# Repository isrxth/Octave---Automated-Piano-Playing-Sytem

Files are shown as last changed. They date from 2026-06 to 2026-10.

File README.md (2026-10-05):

###### 🎹 Project Octave

###### 

###### By Team WeBeSyncing

###### 

###### Project Octave is a high-speed, polyphonic, CNC-style robotic piano playing system. Utilizing a multi-microcontroller architecture, ESP-NOW wireless synchronization, and a custom lookahead kinematic engine, Octave translates standard .mid files into precise physical movements, playing an acoustic piano with superhuman speed and accuracy.

https://github.com/user-attachments/assets/f8b78fd2-65e9-428f-8b61-9593326f1c79

###### ✨ Key Features

###### 

###### &#x20;   Polyphonic "Cluster" Engine: Groups simultaneous MIDI notes and calculates a "Center of Gravity" offset, allowing a rigid solenoid block to perfectly strike multiple keys at once.

###### 

###### &#x20;   Anti-Flood Staggering: Automatically spaces out simultaneous polyphonic WebSocket commands by 15ms to prevent Arduino Uno serial buffer overflow and dropped notes.

###### 

###### &#x20;   Lookahead Background Pre-Positioning: The Web UI calculates future moves and silently drives the stepper carriages into position during the natural musical rests, eliminating mechanical latency.

###### 

###### &#x20;   Strict Hardware Interlock: A closed-loop feedback system using ESP-NOW guarantees that solenoids will never fire while the carriage is in transit, completely protecting the 3D-printed mounts from lateral shear forces.

###### 

###### &#x20;   Dynamic Velocity Control: Maps MIDI velocity data to hardware PWM duty cycles, allowing for expressive, dynamic play (Soft vs. Hard strikes), or strict binary toggling.

###### 

###### &#x20;   Asynchronous Web UI: A beautiful, dark-mode TailwindCSS web interface hosted directly on the ESP32. Features live BPM scaling, dynamic clearance tuning, and an interactive virtual keyboard.

###### 

###### &#x20;   Over-The-Air (OTA) Updates: Fully integrated ElegantOTA allows for flashing firmware to the embedded microcontrollers via Wi-Fi without dismantling the piano hardware.

###### 

###### 🧠 System Architecture

###### 

###### Octave uses a distributed computing model to ensure non-blocking, real-time performance.

###### 1\. The Master Node (ESP32)

###### 

###### &#x20;   Hosts the Web UI (test.html) via ESPAsyncWebServer.

###### 

###### &#x20;   Receives WebSocket commands from the user's browser.

###### 

###### &#x20;   Directly drives the Black Key Solenoids (S1 - S5) via hardware PWM.

###### 

###### &#x20;   Broadcasts MOVE commands to the Stepper Node over ESP-NOW.

###### 

###### &#x20;   Sends Serial commands to the Arduino Uno.

###### 

###### 2\. The Stepper Node (ESP32)

###### 

###### &#x20;   Listens for ESP-NOW packets and drives two NEMA 17 stepper motors using AccelStepper.

###### 

###### &#x20;   Motor 1 (White Carriage): Uses sliding-window nearest-neighbor logic to traverse the white keys.

###### 

###### &#x20;   Motor 2 (Black Carriage): Uses inverted, octave-locked kinematics to perfectly align with the irregular 2-and-3 black key clusters.

###### 

###### &#x20;   Reads physical limit switches and transmits AT\_TARGET packets back to the Master to unlock the software thread.

###### 

###### 3\. The Strike Node (Arduino Uno)

###### 

###### &#x20;   Receives ultra-fast Serial packets from the Master ESP32 via a logic level shifter.

###### 

###### &#x20;   Manages a non-blocking 40ms ballistic state machine for the 7 White Key Solenoids.

###### 

###### &#x20;   Utilizes a custom 1kHz Software PWM engine for digital pins to maintain a 23% low-current hold state, preventing coil burnout.

###### 

###### 🛠️ Hardware Requirements

###### 

###### &#x20;   2x ESP32 Development Boards

###### 

###### &#x20;   1x Arduino Uno R3

###### 

###### &#x20;   2x NEMA 17 Stepper Motors (w/ TMC2209 or A4988 Drivers)

###### 

###### &#x20;   12x 15N Push-Pull Solenoids

###### 

###### &#x20;   3D-Printed Carriages \& Solenoid Mounts

###### 

###### &#x20;   12V / 24V Power Supplies \& Logic Level Converters (HW-209)

###### 

###### 🛜 Changing the Wi-Fi Network Name (SSID)

###### 

###### By default, the Master ESP32 creates a hotspot named POCOF3. Because the Master and Stepper nodes must communicate, their network credentials must match perfectly.

###### 

###### &#x20;   Open solenoid\_esp.cpp (Master) and modify:

###### &#x20;   C++

###### 

###### &#x20;   const char\* hotspotSSID     = "Project\_Octave"; // Your new name

###### &#x20;   const char\* hotspotPassword = "00000000";       // Your new password

###### 

###### &#x20;   Open stepper\_esp.cpp (Stepper) and ensure lines 8 \& 9 match exactly.

###### 

###### &#x20;   Re-flash both ESP32s.

###### 

###### 🚀 Installation \& Setup

###### 1\. Flash the Firmware

###### 

###### &#x20;   Open the project in PlatformIO or the Arduino IDE.

###### 

###### &#x20;   Install the required libraries: ESPAsyncWebServer, AsyncTCP, AccelStepper, ElegantOTA.

###### 

###### &#x20;   Flash solenoid\_esp.cpp and stepper\_esp.cpp to your respective ESP32s.

###### 

###### &#x20;   Flash solenoid\_uno.ino to your Arduino Uno.

###### 

###### 2\. Connect to the UI

###### 

###### &#x20;   Power on the Master ESP32.

###### 

###### &#x20;   Connect your computer/tablet to the Octave Wi-Fi hotspot.

###### 

###### &#x20;   Open your web browser and navigate to the ESP32's IP address (default: http://192.168.4.1).

###### 

###### &#x20;   Enter the IP into the Master Control UI and click CONNECT WS.

###### 

###### 🎹 Polyphony Limits \& Hardware Constraints

###### 

###### While the software fully supports polyphonic MIDI playback, it is bound by the physical laws of the rigid 3D-printed solenoid blocks.

###### 

###### &#x20;   The Span Limit: The system can play multiple notes at the exact same time, but they must physically fit under the 7-solenoid white carriage or the 5-solenoid black carriage. \* The Outlier Drop: If a MIDI file demands a C3 and a C5 simultaneously, the carriage cannot stretch. The software's Cluster Engine will calculate a "Center of Gravity" to cover the densest cluster of notes and safely ignore the unreachable outliers to prevent the motors from destroying the mounts.

###### 

###### 🎯 Usage \& Tuning

###### 

###### Once connected to the UI, you can calibrate Octave to match your specific physical build:

###### 

###### &#x20;   White Home / Black Home: Adjust these steps to perfectly align the 3D-printed carriages over the physical C3 octave. (Note: Black Home uses inverted kinematics, so its home step is a high value like 2400).

###### 

###### &#x20;   Clearance (ms): The mechanical time allowed for the 15N solenoid springs to pull the metal slugs out of the keybed before the stepper motors are allowed to move. Lower this value for faster songs, but ensure the slugs clear the keys to avoid lateral dragging.

###### 

###### &#x20;   Target BPM: The live tempo scaler. You can speed up or slow down a loaded MIDI file in real-time.

###### 

###### 📝 License \& Credits

## Schematics & PCB

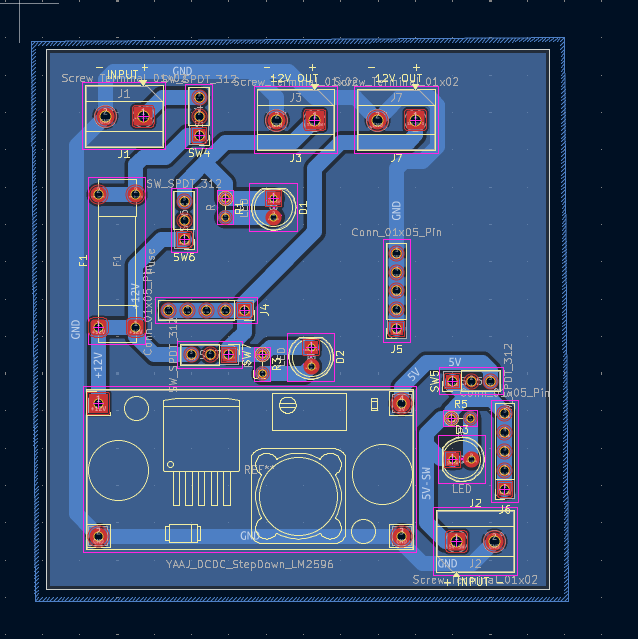
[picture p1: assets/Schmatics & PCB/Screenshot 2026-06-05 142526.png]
Schematic and PCB overview


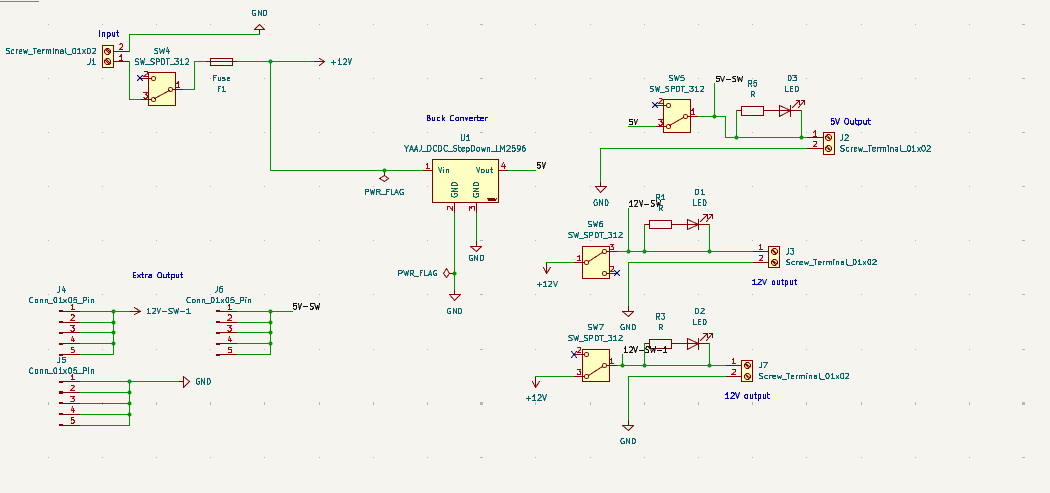
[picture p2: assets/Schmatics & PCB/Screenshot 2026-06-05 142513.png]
Schematic detail


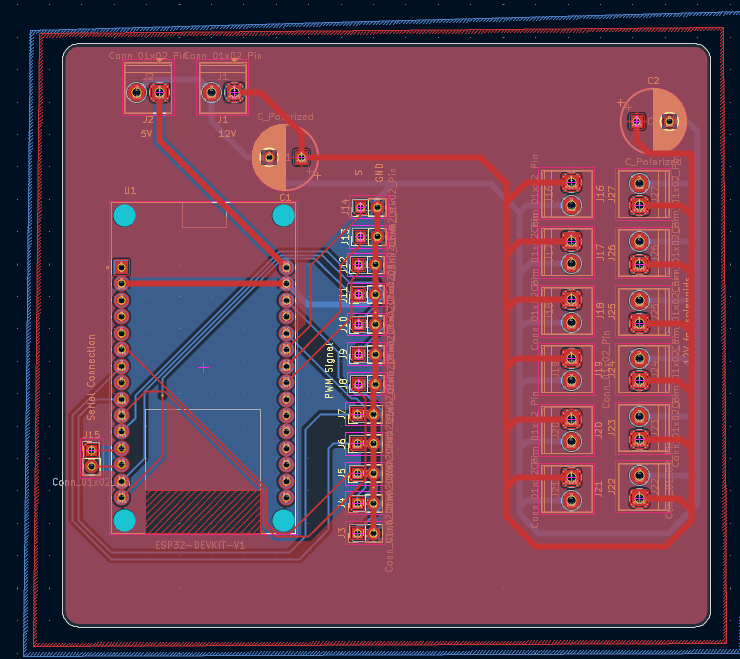
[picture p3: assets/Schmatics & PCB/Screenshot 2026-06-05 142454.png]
PCB detail


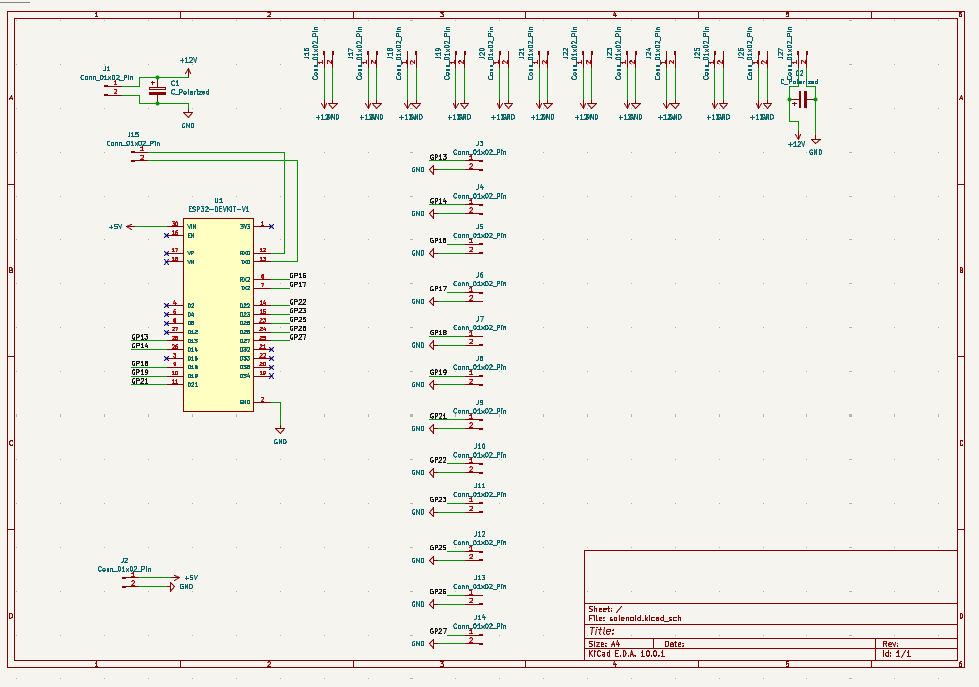
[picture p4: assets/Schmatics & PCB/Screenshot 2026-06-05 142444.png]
Power board schematic


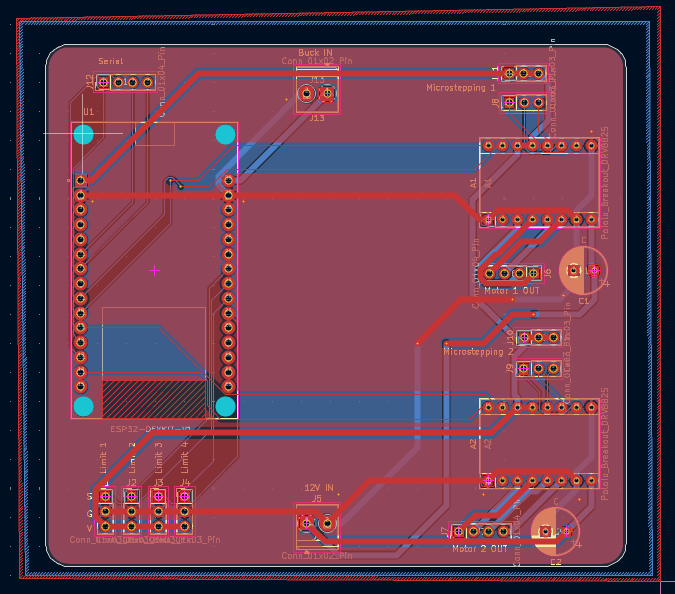
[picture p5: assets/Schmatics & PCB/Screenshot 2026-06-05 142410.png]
Solenoid board schematic


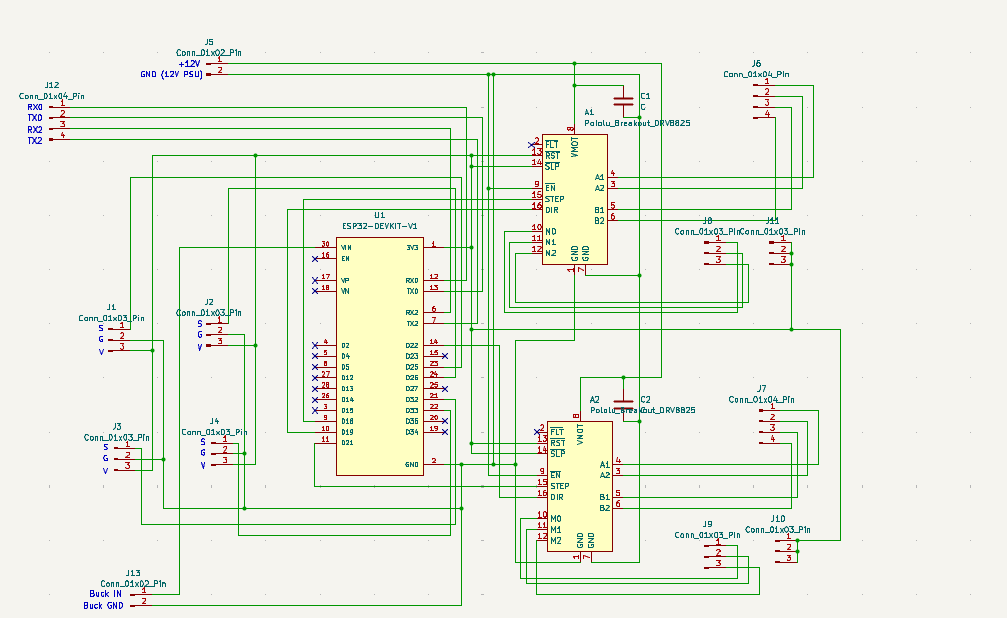
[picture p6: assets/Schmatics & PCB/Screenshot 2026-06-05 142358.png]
Stepper board schematic


###### 

###### Developed by Team WeBeSyncing.

###### Built for the intersection of Embedded Systems, Mechanical Engineering, and Music.

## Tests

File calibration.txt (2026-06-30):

C 810
D 800
E 780
F 770
G 750
A 750
B 730

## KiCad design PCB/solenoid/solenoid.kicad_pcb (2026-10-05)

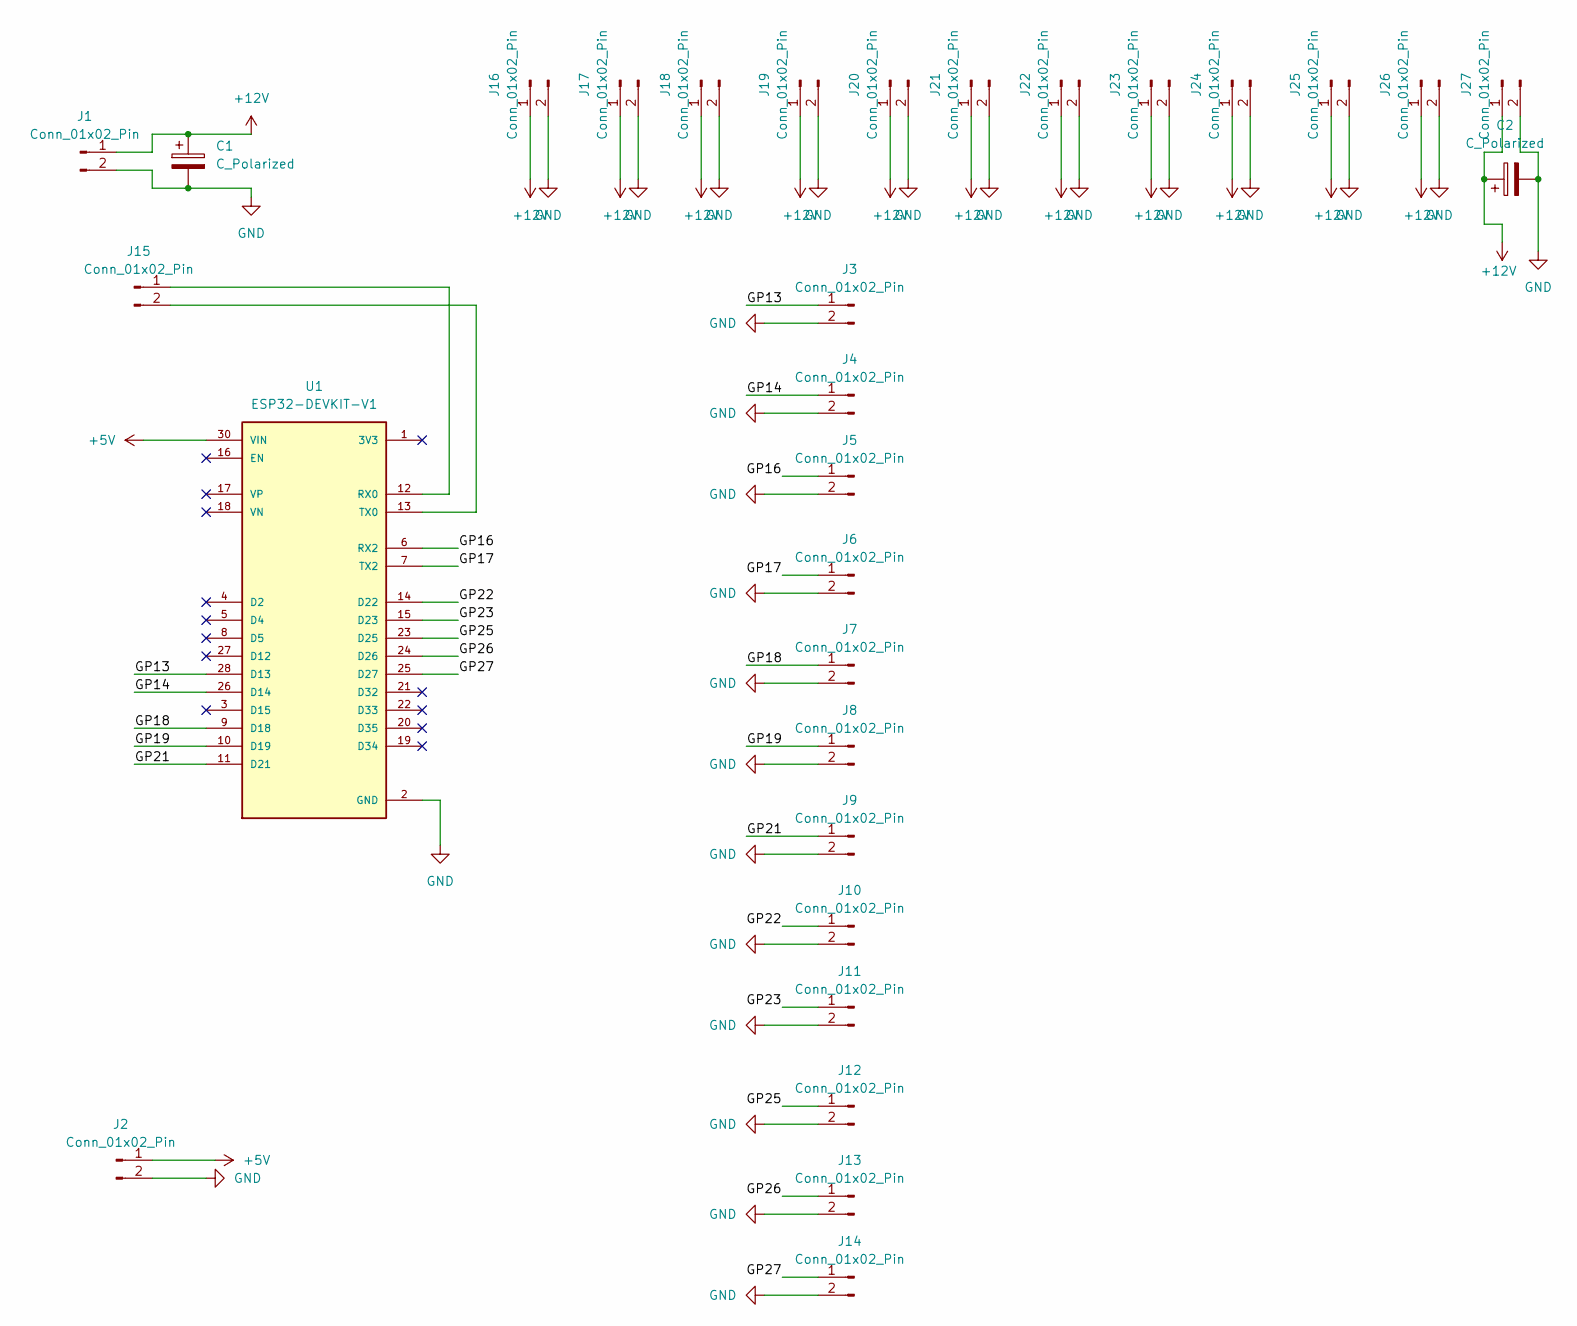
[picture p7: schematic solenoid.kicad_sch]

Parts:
C1, C2: C_Polarized; CP_Radial_D10.0mm_P5.00mm
J1, J2, J16, J17, J18, J19, J20, J21, J22, J23, J24, J25, J26, J27: Conn_01x02_Pin; TerminalBlock_Phoenix_PT-1,5-2-3.5-H_1x02_P3.50mm_Horizontal
J3, J4, J5, J6, J7, J8, J9, J10, J11, J12, J13, J14, J15: Conn_01x02_Pin; PinHeader_1x02_P2.54mm_Vertical
U1: ESP32-DEVKIT-V1; MODULE_ESP32_DEVKIT_V1; PARTREV N/A

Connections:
+5V: J2.1, U1.30 (VIN)
+12V: C1.1, C2.1, J1.1, J16.1, J17.1, J18.1, J19.1, J20.1, J21.1, J22.1, J23.1, J24.1, J25.1, J26.1, J27.1
/GP13: J3.1, U1.28 (D13)
/GP14: J4.1, U1.26 (D14)
/GP16: J5.1, U1.6 (RX2)
/GP17: J6.1, U1.7 (TX2)
/GP18: J7.1, U1.9 (D18)
/GP19: J8.1, U1.10 (D19)
/GP21: J9.1, U1.11 (D21)
/GP22: J10.1, U1.14 (D22)
/GP23: J11.1, U1.15 (D23)
/GP25: J12.1, U1.23 (D25)
/GP26: J13.1, U1.24 (D26)
/GP27: J14.1, U1.25 (D27)
GND: C1.2, C2.2, J1.2, J2.2, J3.2, J4.2, J5.2, J6.2, J7.2, J8.2, J9.2, J10.2, J11.2, J12.2, J13.2, J14.2, J16.2, J17.2, J18.2, J19.2, J20.2, J21.2, J22.2, J23.2, J24.2, J25.2, J26.2, J27.2, U1.2 (GND), U1.29 (GND)
unnamed: J15.1, U1.12 (RX0)
unnamed: J15.2, U1.13 (TX0)

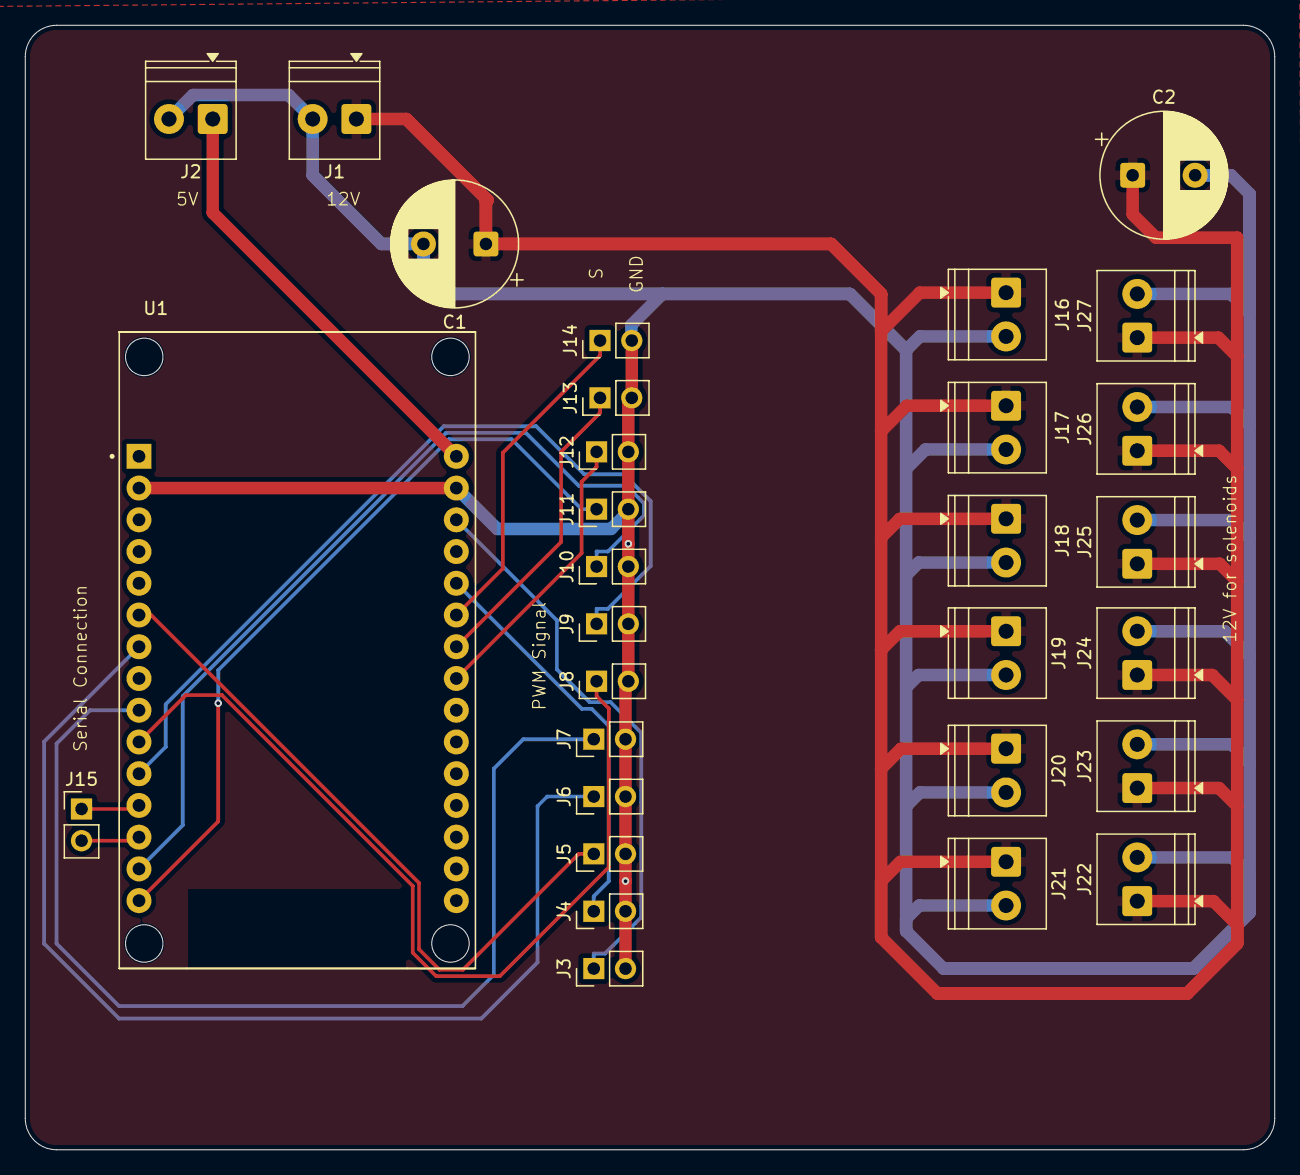
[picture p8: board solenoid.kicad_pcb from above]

Board: 2 copper layers, 100.0 x 90.0 mm, 30 parts (0 on the bottom side), 17 nets.

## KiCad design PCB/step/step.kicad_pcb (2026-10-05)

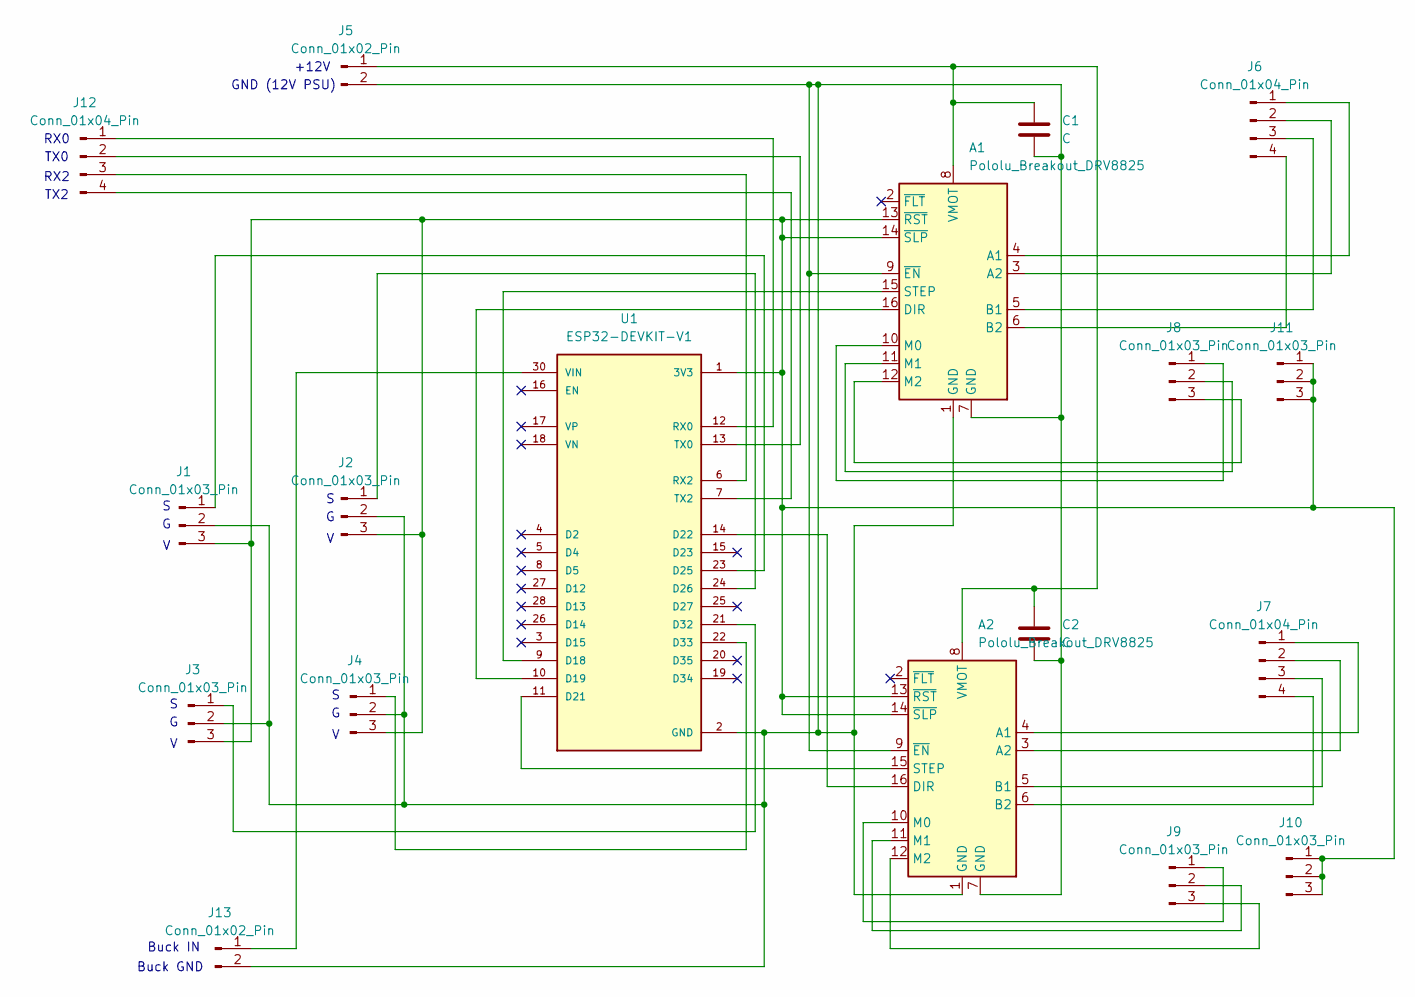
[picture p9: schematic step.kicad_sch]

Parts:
A1, A2: Pololu_Breakout_DRV8825; Pololu_Breakout-16_15.2x20.3mm
C1, C2: C; CP_Radial_D8.0mm_P3.50mm
J1, J2, J3, J4, J8, J9, J10, J11: Conn_01x03_Pin; PinHeader_1x03_P2.54mm_Vertical
J5, J13: Conn_01x02_Pin; TerminalBlock_Phoenix_PT-1,5-2-3.5-H_1x02_P3.50mm_Horizontal
J6, J7, J12: Conn_01x04_Pin; PinHeader_1x04_P2.54mm_Vertical
U1: ESP32-DEVKIT-V1; MODULE_ESP32_DEVKIT_V1; PARTREV N/A

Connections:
GND: A1.1 (GND), A1.7 (GND), A1.9 (~EN), A2.1 (GND), A2.7 (GND), A2.9 (~EN), C1.2, C2.2, J1.2, J2.2, J3.2, J4.2, J5.2, J13.2, U1.2 (GND), U1.29 (GND)
unnamed: A1.4 (A1), J6.1
unnamed: A1.3 (A2), J6.2
unnamed: A1.5 (B1), J6.3
unnamed: A1.6 (B2), J6.4
unnamed: A1.16 (DIR), U1.10 (D19)
unnamed: A1.10 (M0), J8.1
unnamed: A1.11 (M1), J8.2
unnamed: A1.12 (M2), J8.3
unnamed: A1.15 (STEP), U1.9 (D18)
unnamed: A1.8 (VMOT), A2.8 (VMOT), C1.1, C2.1, J5.1
unnamed: A1.13 (~RST), A1.14 (~SLP), A2.13 (~RST), A2.14 (~SLP), J1.3, J2.3, J3.3, J4.3, J10.1, J10.2, J10.3, J11.1, J11.2, J11.3, U1.1 (3V3)
unnamed: A2.4 (A1), J7.1
unnamed: A2.3 (A2), J7.2
unnamed: A2.5 (B1), J7.3
unnamed: A2.6 (B2), J7.4
unnamed: A2.16 (DIR), U1.14 (D22)
unnamed: A2.10 (M0), J9.1
unnamed: A2.11 (M1), J9.2
unnamed: A2.12 (M2), J9.3
unnamed: A2.15 (STEP), U1.11 (D21)
unnamed: J1.1, U1.23 (D25)
unnamed: J2.1, U1.24 (D26)
unnamed: J3.1, U1.21 (D32)
unnamed: J4.1, U1.22 (D33)
unnamed: J12.1, U1.12 (RX0)
unnamed: J12.2, U1.13 (TX0)
unnamed: J12.3, U1.6 (RX2)
unnamed: J12.4, U1.7 (TX2)
unnamed: J13.1, U1.30 (VIN)

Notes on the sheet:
RX2
Buck GND
Buck IN
TX2
RX0
GND (12V PSU)
+12V
TX0

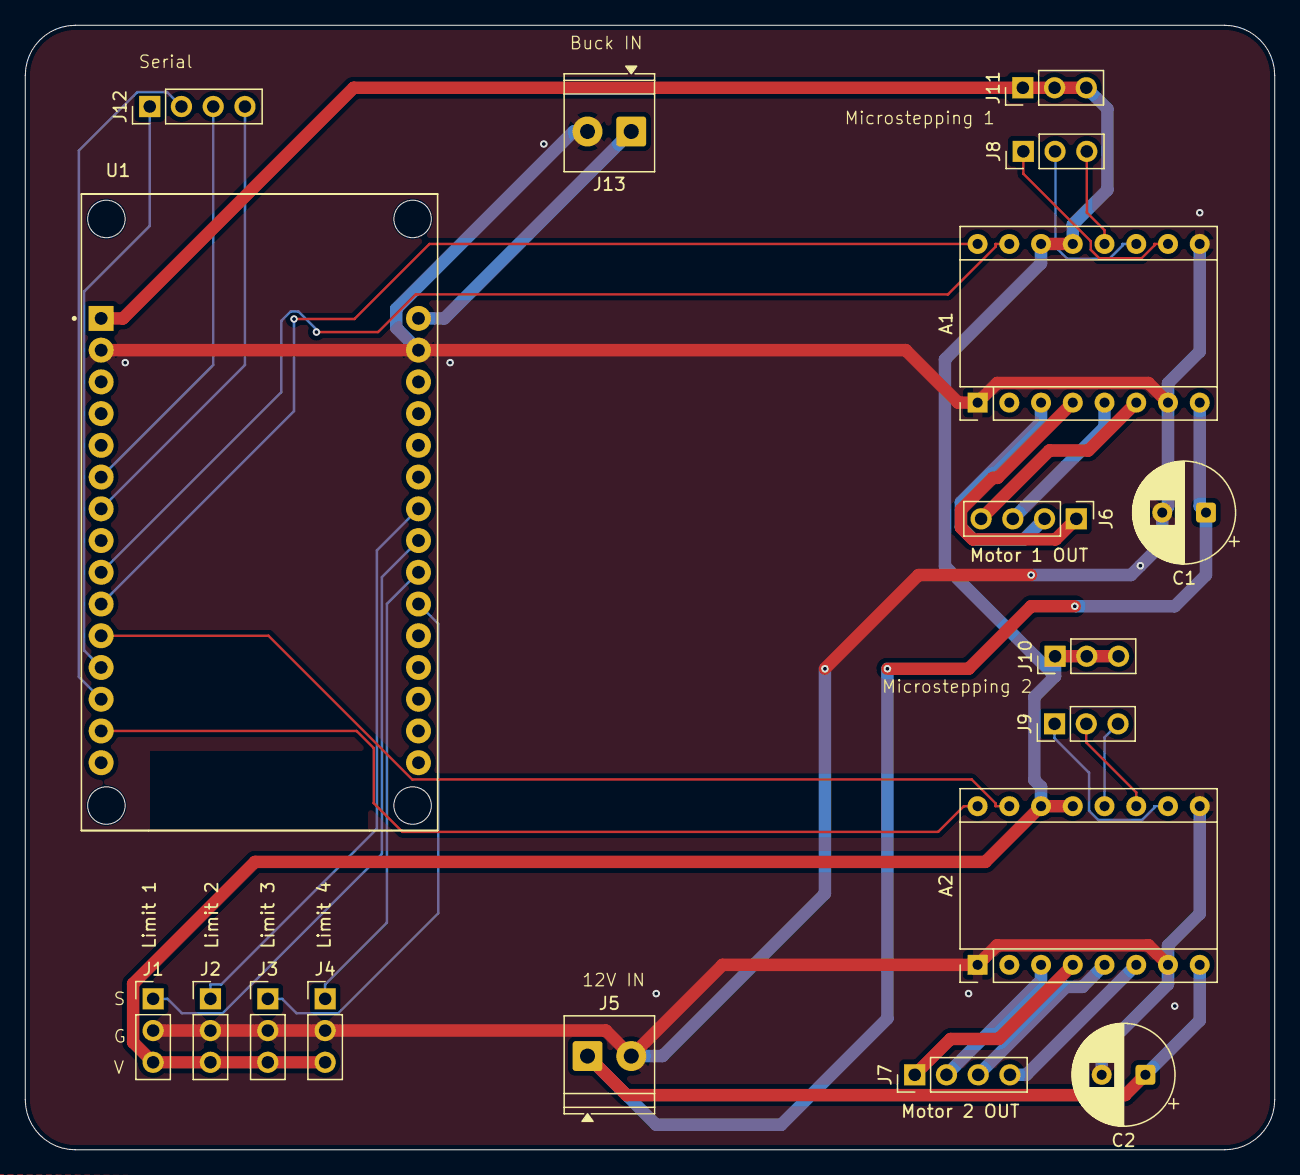
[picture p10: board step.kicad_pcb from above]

Board: 2 copper layers, 100.0 x 90.0 mm, 18 parts (0 on the bottom side), 30 nets.

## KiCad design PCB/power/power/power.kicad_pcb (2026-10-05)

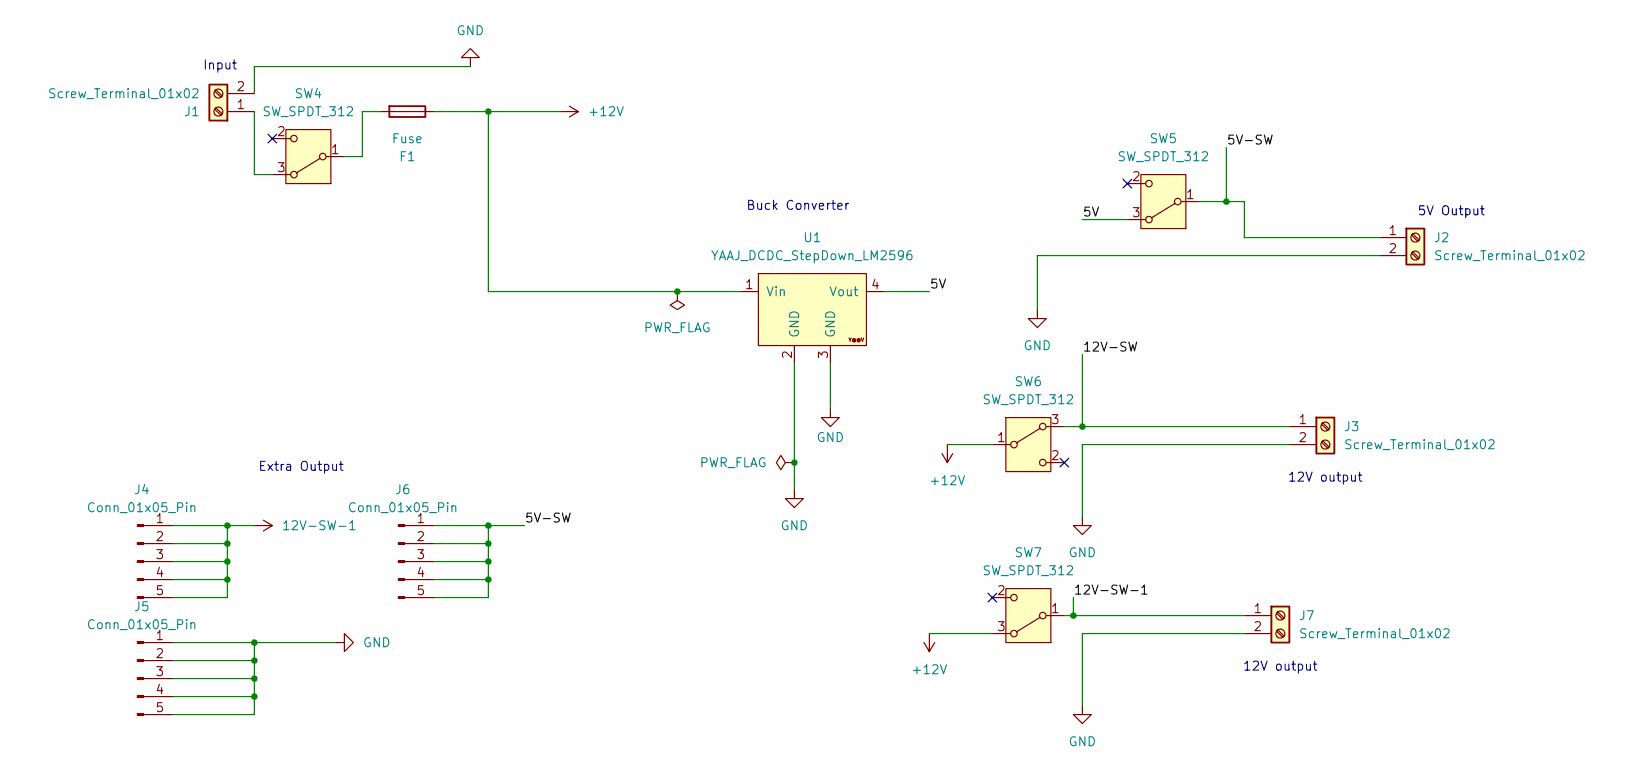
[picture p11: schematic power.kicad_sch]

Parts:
F1: Fuse; Fuseholder_Clip-5x20mm_Bel_FC-203-22_Lateral_P17.80x5.00mm_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
J1, J2, J3, J7: Screw_Terminal_01x02; TerminalBlock_MetzConnect_Type101_RT01602HBWC_1x02_P5.08mm_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
J4, J5, J6: Conn_01x05_Pin; PinSocket_1x05_P2.54mm_Vertical
SW4, SW5, SW6, SW7: SW_SPDT_312; PinHeader_1x03_P2.54mm_Vertical
U1: YAAJ_DCDC_StepDown_LM2596

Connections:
12V-SW-1: J4.1, J4.2, J4.3, J4.4, J4.5, J7.1, SW7.1 (B)
+12V: F1.1, SW6.1 (B), SW7.3 (A), U1.1 (Vin)
/5V: SW5.3 (A), U1.4 (Vout)
/5V-SW: J2.1, J6.1, J6.2, J6.3, J6.4, J6.5, SW5.1 (B)
/12V-SW: J3.1, SW6.3 (A)
GND: J1.2, J2.2, J3.2, J5.1, J5.2, J5.3, J5.4, J5.5, J7.2, U1.2 (GND), U1.3 (GND)
unnamed: J1.1, SW4.3 (A)
unnamed: F1.2, SW4.1 (B)

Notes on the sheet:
12V output
Buck Converter
5V Output
Extra Output
Input

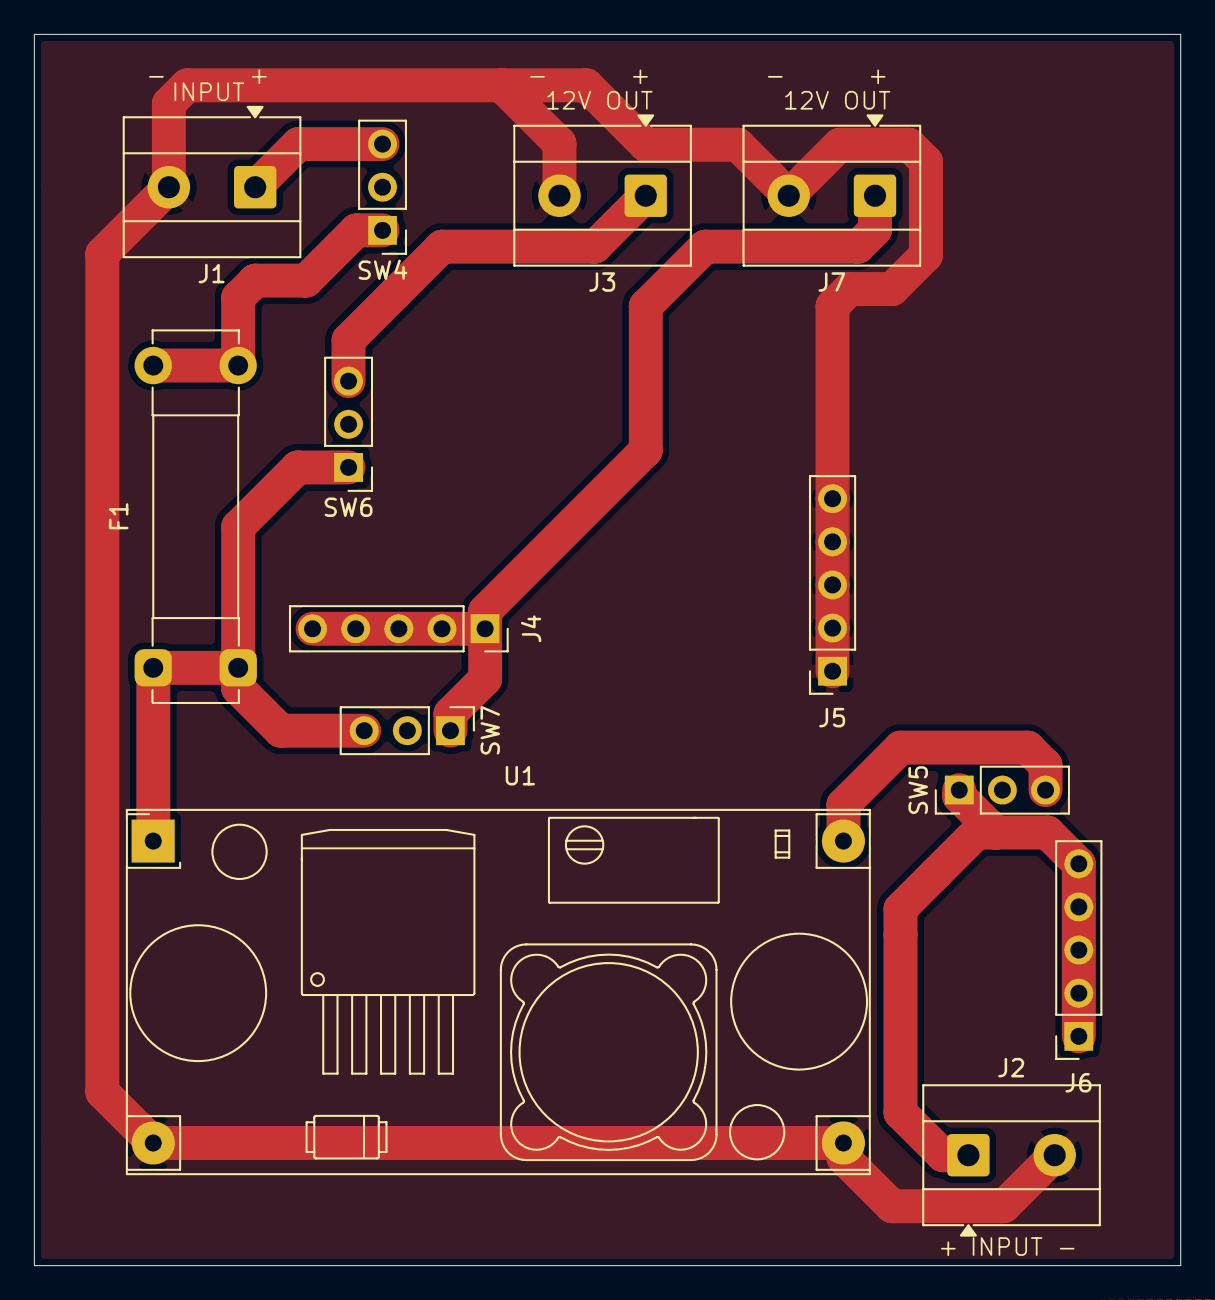
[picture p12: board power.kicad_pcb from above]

Board: 2 copper layers, 67.5 x 72.5 mm, 13 parts (0 on the bottom side), 8 nets.

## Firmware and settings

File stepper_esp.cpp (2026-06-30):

// --- Firmware for Team Obsidian Robotic Piano ---
// Module: Stepper Controller ESP32 (Slave)

#include <Arduino.h>
#include <WiFi.h>
#include <esp_now.h>
#include <AccelStepper.h>
#include <ElegantOTA.h>
#include <WebServer.h>

const char* hotspotSSID     = "POCOF3";
const char* hotspotPassword = "00000000";

WebServer server(80);

AccelStepper stepper(1, 18, 19);
AccelStepper stepper2(1, 21, 22);

#define LIMIT_M1_LEFT  25
#define LIMIT_M1_RIGHT 26
#define LIMIT_M2_LEFT  32
#define LIMIT_M2_RIGHT 33

// --- CONFIGURATION FOR SNAPPY MOVEMENT ---
int  runSpeedVal   = 3500;  
int  accelVal      = 3000; // Controlled snappy acceleration profile

volatile long targetM1 = 0;
volatile long targetM2 = 0;
volatile bool newCmdM1 = false;
volatile bool newCmdM2 = false;

// Hardware Flags
bool m1WasMoving = false;
bool m2WasMoving = false;
volatile bool triggerZeroCmd = false; // Safe flag to trigger quick-zeroing outside of ISR

struct Message { char text[100]; };
uint8_t receiverMac[] = {0xB4, 0x8A, 0x0A, 0xB2, 0xAA, 0xBC};
Message msg;

// Function to send target confirmation status messages back to the Master Solenoid ESP32
void sendFeedback(const char* logMsg) {
  Message reply;
  strncpy(reply.text, logMsg, sizeof(reply.text) - 1);
  reply.text[sizeof(reply.text) - 1] = '\0';
  esp_now_send(receiverMac, (uint8_t *) &reply, sizeof(reply));
}

void OnDataRecv(const uint8_t *mac_addr, const uint8_t *incomingData, int len) {
  Message incomingMsg;
  memcpy(&incomingMsg, incomingData, min(len, (int)sizeof(incomingMsg)));
  incomingMsg.text[sizeof(incomingMsg.text) - 1] = '\0';
  
  if (strncmp(incomingMsg.text, "MOVE,", 5) == 0) {
    char motorDigit = incomingMsg.text[6];
    long targetStep = atol(incomingMsg.text + 8);
    if (motorDigit == '1') { targetM1 = targetStep; newCmdM1 = true; }
    else if (motorDigit == '2') { targetM2 = targetStep; newCmdM2 = true; }
  }
  else if (strncmp(incomingMsg.text, "CFG,SPD,", 8) == 0) {
    runSpeedVal = atoi(incomingMsg.text + 8);
    stepper.setMaxSpeed(runSpeedVal);
    stepper2.setMaxSpeed(runSpeedVal);
    Serial.printf("[CFG] Speed updated to: %d\n", runSpeedVal);
  }
  else if (strncmp(incomingMsg.text, "CFG,ACC,", 8) == 0) {
    accelVal = atoi(incomingMsg.text + 8);
    stepper.setAcceleration(accelVal);
    stepper2.setAcceleration(accelVal);
    Serial.printf("[CFG] Accel updated to: %d\n", accelVal);
  }
  // --- NEW: QUICK-ZERO TRIGGER ---
  else if (strncmp(incomingMsg.text, "CMD,ZERO", 8) == 0) {
    triggerZeroCmd = true;
  }
}

// Initial full calibration run on boot
void home() {
  Serial.println("Initial Boot Homing Calibration...");

  stepper.setMaxSpeed(1000);
  stepper2.setMaxSpeed(1000);
  stepper.setAcceleration(1000);
  stepper2.setAcceleration(1000);

  stepper.setSpeed(-500);
  stepper2.setSpeed(-500);

  bool m1Homed = false, m2Homed = false;
  while (!m1Homed || !m2Homed) {
    if (!m1Homed) {
      if (digitalRead(LIMIT_M1_LEFT) == LOW) {
        stepper.setSpeed(0);
        stepper.setCurrentPosition(0); 
        m1Homed = true;
      } else { stepper.runSpeed(); }
    }
    if (!m2Homed) {
      if (digitalRead(LIMIT_M2_LEFT) == LOW) {
        stepper2.setSpeed(0);
        stepper2.setCurrentPosition(0); 
        m2Homed = true;
      } else { stepper2.runSpeed(); }
    }
  }

  stepper.setSpeed(500);
  stepper2.setSpeed(500);
  bool m1MaxFound = false, m2MaxFound = false;
  long trackLengthM1 = 0, trackLengthM2 = 0;

  while (!m1MaxFound || !m2MaxFound) {
    if (!m1MaxFound) {
      if (digitalRead(LIMIT_M1_RIGHT) == LOW) {
        stepper.setSpeed(0);
        trackLengthM1 = stepper.currentPosition();
        m1MaxFound = true;
      } else { stepper.runSpeed(); }
    }
    if (!m2MaxFound) {
      if (digitalRead(LIMIT_M2_RIGHT) == LOW) {
        stepper2.setSpeed(0);
        trackLengthM2 = stepper2.currentPosition();
        m2MaxFound = true;
      } else { stepper2.runSpeed(); }
    }
  }

  stepper.setMaxSpeed(runSpeedVal);
  stepper.setAcceleration(accelVal);
  stepper2.setMaxSpeed(runSpeedVal);
  stepper2.setAcceleration(accelVal);

  stepper.moveTo(0);
  stepper2.moveTo(0);
  
  while (stepper.distanceToGo() != 0 || stepper2.distanceToGo() != 0) {
    stepper.run(); 
    stepper2.run();
  }
  Serial.println("Initial Boot Homing Complete. System initialized at absolute zero.");
}

// --- NEW: FAST ZEROING SEQUENCE ---
// Only moves left to re-sync steps, entirely bypassing the max track length measurement
void quickZero() {
  Serial.println("Quick Zeroing: Re-syncing carriages to Left Limits...");

  stepper.setMaxSpeed(1000);
  stepper2.setMaxSpeed(1000);
  stepper.setSpeed(-500);
  stepper2.setSpeed(-500);

  bool m1Zeroed = false, m2Zeroed = false;
  while (!m1Zeroed || !m2Zeroed) {
    if (!m1Zeroed) {
      if (digitalRead(LIMIT_M1_LEFT) == LOW) {
        stepper.setSpeed(0);
        stepper.setCurrentPosition(0); 
        m1Zeroed = true;
      } else { stepper.runSpeed(); }
    }
    if (!m2Zeroed) {
      if (digitalRead(LIMIT_M2_LEFT) == LOW) {
        stepper2.setSpeed(0);
        stepper2.setCurrentPosition(0); 
        m2Zeroed = true;
      } else { stepper2.runSpeed(); }
    }
  }

  // Restore high-performance variables
  stepper.setMaxSpeed(runSpeedVal);
  stepper.setAcceleration(accelVal);
  stepper2.setMaxSpeed(runSpeedVal);
  stepper2.setAcceleration(accelVal);
  
  Serial.println("Quick Zero Complete. System perfectly synchronized at step 0.");
}

bool otaModeActive = false;

void setup() {
  Serial.begin(115200);
  pinMode(LIMIT_M1_LEFT,  INPUT_PULLUP);
  pinMode(LIMIT_M1_RIGHT, INPUT_PULLUP);
  pinMode(LIMIT_M2_LEFT,  INPUT_PULLUP);
  pinMode(LIMIT_M2_RIGHT, INPUT_PULLUP);

  if (digitalRead(LIMIT_M1_LEFT) == LOW || digitalRead(LIMIT_M2_LEFT) == LOW) {
    otaModeActive = true;
  }

  WiFi.mode(WIFI_STA);
  WiFi.setSleep(false);
  WiFi.begin(hotspotSSID, hotspotPassword);

  if (otaModeActive) {
    while (WiFi.status() != WL_CONNECTED) delay(500);
    server.on("/", []() { server.send(200, "text/plain", "OTA Mode"); });
    server.begin();
    ElegantOTA.begin(&server);
  } else {
    while (WiFi.status() != WL_CONNECTED) delay(500);
    home();
    if (esp_now_init() == ESP_OK) {
      esp_now_register_recv_cb(esp_now_recv_cb_t(OnDataRecv));
      esp_now_peer_info_t peerInfo = {};
      memcpy(peerInfo.peer_addr, receiverMac, 6);
      peerInfo.channel = 0;
      peerInfo.encrypt = false;
      esp_now_add_peer(&peerInfo);
    }
  }
}

void loop() {
  if (otaModeActive) {
    server.handleClient();
    ElegantOTA.loop();
    return;
  }

  // --- Safe Execution of Quick-Zero outside of ISR ---
  if (triggerZeroCmd) {
    triggerZeroCmd = false; // Reset flag
    Serial.println("[CMD] Auto Quick-Zero Initiated by Master UI...");
    quickZero();
    sendFeedback("ZERO_COMPLETE");
    return; // Skip normal loop execution for this cycle
  }

  // Read physical states of all end-stops
  bool m1LeftPressed  = (digitalRead(LIMIT_M1_LEFT) == LOW);
  bool m1RightPressed = (digitalRead(LIMIT_M1_RIGHT) == LOW);
  bool m2LeftPressed  = (digitalRead(LIMIT_M2_LEFT) == LOW);
  bool m2RightPressed = (digitalRead(LIMIT_M2_RIGHT) == LOW);

  // --- 1. FIXED DEBOUNCED SAFETY INTERRUPTS & REBOUNDS ---
  
  // Motor 1 Left Limit
  if (m1LeftPressed && stepper.distanceToGo() < 0) {
    delayMicroseconds(500); // Filter electrical interference noise
    if (digitalRead(LIMIT_M1_LEFT) == LOW) {
      stepper.stop();
      stepper.setCurrentPosition(0);
      stepper.moveTo(15); 
    }
  }
  // Motor 1 Right Limit
  if (m1RightPressed && stepper.distanceToGo() > 0) {
    delayMicroseconds(500);
    if (digitalRead(LIMIT_M1_RIGHT) == LOW) {
      stepper.stop();
      stepper.setCurrentPosition(stepper.currentPosition());
      stepper.moveTo(stepper.currentPosition() - 15); // Rebound left
    }
  }
  
  // Motor 2 Left Limit
  if (m2LeftPressed && stepper2.distanceToGo() < 0) {
    delayMicroseconds(500);
    if (digitalRead(LIMIT_M2_LEFT) == LOW) {
      stepper2.stop();
      stepper2.setCurrentPosition(0);
      stepper2.moveTo(15); // Rebound right
    }
  }
  // Motor 2 Right Limit
  if (m2RightPressed && stepper2.distanceToGo() > 0) {
    delayMicroseconds(500);
    if (digitalRead(LIMIT_M2_RIGHT) == LOW) {
      stepper2.stop();
      stepper2.setCurrentPosition(stepper2.currentPosition());
      stepper2.moveTo(stepper2.currentPosition() - 15); // Rebound left
    }
  }

  // --- 2. INBOUND AIR PACKETS HANDLING ---
  if (newCmdM1) {
    newCmdM1 = false;
    if (m1LeftPressed && targetM1 < stepper.currentPosition()) {
      Serial.println("[SAFETY] Command blocked: Motor 1 at Left boundary.");
      sendFeedback("AT_TARGET"); 
    } 
    else if (m1RightPressed && targetM1 > stepper.currentPosition()) {
      Serial.println("[SAFETY] Command blocked: Motor 1 at Right boundary.");
      sendFeedback("AT_TARGET"); 
    } 
    else {
      stepper.moveTo(targetM1);
      m1WasMoving = true;
    }
  }

  if (newCmdM2) {
    newCmdM2 = false;
    if (m2LeftPressed && targetM2 < stepper2.currentPosition()) {
      Serial.println("[SAFETY] Command blocked: Motor 2 at Left boundary.");
      sendFeedback("AT_TARGET"); 
    } 
    else if (m2RightPressed && targetM2 > stepper2.currentPosition()) {
      Serial.println("[SAFETY] Command blocked: Motor 2 at Right boundary.");
      sendFeedback("AT_TARGET"); 
    } 
    else {
      stepper2.moveTo(targetM2);
      m2WasMoving = true;
    }
  }

  // Smooth continuous execution via AccelStepper
  stepper.run();
  stepper2.run();

  // --- 3. HARDWARE REAL-TIME TARGET DETECTOR ---
  if (m1WasMoving && stepper.distanceToGo() == 0) {
    m1WasMoving = false;
    sendFeedback("AT_TARGET");
  }
  if (m2WasMoving && stepper2.distanceToGo() == 0) {
    m2WasMoving = false;
    sendFeedback("AT_TARGET");
  }
}

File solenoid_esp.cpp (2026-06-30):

#include <Arduino.h>
#define ELEGANTOTA_USE_ASYNC_WEBSERVER 1
#include <WiFi.h>
#include <AsyncTCP.h>
#include <ESPAsyncWebServer.h>
#include <esp_now.h>
#include <ElegantOTA.h>
#include <esp_system.h>

// --- Pin Assignments ---
#define S1 13
#define S2 14
#define S3 16
#define S4 19 
#define S5 18

const int numLocalSolenoids = 5;
const int solenoidPins[numLocalSolenoids] = {S1, S2, S3, S4, S5};

// --- Solenoid State Machine ---
unsigned long strikeStartTime[numLocalSolenoids] = {0};
unsigned long holdStartTime[numLocalSolenoids]   = {0};
bool isStriking[numLocalSolenoids] = {false};
bool isHolding[numLocalSolenoids]  = {false};

int POWER_HOLD = 60;
int strikeTime = 40;
int holdTime   = 40; // <--- MASSIVE REDUCTION: Changed from 200ms to 40ms for fast staccato strikes

// --- WiFi ---
const char* hotspotSSID     = "POCOF3";
const char* hotspotPassword = "00000000";

AsyncWebServer server(80);
AsyncWebSocket ws("/ws");

// Use a fixed char buffer instead of String for logText
#define LOG_BUF_SIZE 2048
char logBuf[LOG_BUF_SIZE];
int  logBufLen = 0;

void appendToLogBuf(const char* msg) {
  int msgLen = strlen(msg);
  int needed = msgLen + 1; // +1 for newline
  if (logBufLen + needed >= LOG_BUF_SIZE) {
    int half = LOG_BUF_SIZE / 2;
    memmove(logBuf, logBuf + half, logBufLen - half);
    logBufLen -= half;
    logBuf[logBufLen] = '\0';
  }
  memcpy(logBuf + logBufLen, msg, msgLen);
  logBufLen += msgLen;
  logBuf[logBufLen++] = '\n';
  logBuf[logBufLen]   = '\0';
}

// --- Safe pending log queue (for ESP-NOW / other ISR contexts) ---
#define PENDING_LOG_MAX 16
#define PENDING_MSG_LEN 120
char pendingLogs[PENDING_LOG_MAX][PENDING_MSG_LEN];
volatile int pendingHead = 0;
volatile int pendingTail = 0;

void enqueuePendingLog(const char* msg) {
  int next = (pendingTail + 1) % PENDING_LOG_MAX;
  if (next != pendingHead) {
    strncpy(pendingLogs[pendingTail], msg, PENDING_MSG_LEN - 1);
    pendingLogs[pendingTail][PENDING_MSG_LEN - 1] = '\0';
    pendingTail = next;
  }
}

void flushPendingLogs() {
  while (pendingHead != pendingTail) {
    const char* msg = pendingLogs[pendingHead];
    appendToLogBuf(msg);
    ws.textAll(msg);
    pendingHead = (pendingHead + 1) % PENDING_LOG_MAX;
  }
}

void addLog(const char* msg) {
  appendToLogBuf(msg);
  ws.textAll(msg);
}

void addLog(const String& msg) { addLog(msg.c_str()); }

struct EspNowMessage { char text[100]; };

// --- Forward declarations ---
void playNote(int noteID, int velocity);

// --- WebSocket event handler ---
void onWsEvent(AsyncWebSocket *srv, AsyncWebSocketClient *client,
               AwsEventType type, void *arg, uint8_t *data, size_t len) {

  if (type == WS_EVT_CONNECT) {
    Serial.printf("[WS] Client #%u connected  heap=%u\n",
                  client->id(), ESP.getFreeHeap());
    if (logBufLen > 0) {
      client->text(logBuf); 
    }

  } else if (type == WS_EVT_DISCONNECT) {
    Serial.printf("[WS] Client #%u disconnected heap=%u\n",
                  client->id(), ESP.getFreeHeap());

  } else if (type == WS_EVT_DATA) {
    AwsFrameInfo *info = (AwsFrameInfo*)arg;
    if (info->final && info->index == 0 && info->len == len
        && info->opcode == WS_TEXT && len < 32) {
      data[len] = 0;
      
      // 1. Parse Solenoid "HIT,<id>,<vel>" commands
      if (strncmp((char*)data, "HIT,", 4) == 0) {
        int id = 0, vel = 0;
        sscanf((char*)data + 4, "%d,%d", &id, &vel);
        if (id > 0) playNote(id, vel);
      } 
      // 2. Parse Stepper "MOVE", "CFG", or "CMD" commands to forward via ESP-NOW
      else if (strncmp((char*)data, "MOVE,", 5) == 0 || strncmp((char*)data, "CFG,", 4) == 0 || strncmp((char*)data, "CMD,", 4) == 0) {
        EspNowMessage moveMsg;
        strncpy(moveMsg.text, (char*)data, sizeof(moveMsg.text) - 1);
        moveMsg.text[sizeof(moveMsg.text) - 1] = '\0';
        
        // Send movement target to the BROADCAST MAC ADDRESS
        uint8_t broadcastMac[] = {0xFF, 0xFF, 0xFF, 0xFF, 0xFF, 0xFF};
        esp_now_send(broadcastMac, (uint8_t *) &moveMsg, sizeof(moveMsg));
        
        char buf[60];
        snprintf(buf, sizeof(buf), "[ESP-NOW TX] %s", moveMsg.text);
        addLog(buf);
      }
    }

  } else if (type == WS_EVT_ERROR) {
    Serial.printf("[WS] Client #%u error\n", client->id());
  }
}

// --- ESP-NOW callback ---
void OnDataRecv(const uint8_t *mac_addr, const uint8_t *incomingData, int len) {
  EspNowMessage msg;
  int copyLen = min(len, (int)sizeof(msg) - 1);
  memcpy(&msg, incomingData, copyLen);
  msg.text[copyLen] = '\0';
  
  // Forward everything including status flags right into the Web UI logs pipeline
  char buf[120];
  snprintf(buf, sizeof(buf), "[ESP-NOW] %s", msg.text);
  enqueuePendingLog(buf);
}

// --- Solenoid control ---
void triggerLocalSolenoidAsync(int index, int strikePower) {
  if (index >= 0 && index < numLocalSolenoids) {
    isStriking[index]      = true;
    isHolding[index]       = false;
    strikeStartTime[index] = millis();
    analogWrite(solenoidPins[index], strikePower);
  }
}

void updateSolenoidStateMachines() {
  unsigned long now = millis();
  for (int i = 0; i < numLocalSolenoids; i++) {
    if (isStriking[i] && (now - strikeStartTime[i] >= (unsigned long)strikeTime)) {
      isStriking[i]    = false;
      isHolding[i]     = true;
      holdStartTime[i] = now;
      analogWrite(solenoidPins[i], POWER_HOLD);
    }
    if (isHolding[i] && (now - holdStartTime[i] >= (unsigned long)holdTime)) {
      isHolding[i] = false;
      analogWrite(solenoidPins[i], 0);
    }
  }
}

// --- Note router ---
void playNote(int noteID, int velocity) {
  char buf[60];
  if (noteID >= 1 && noteID <= 5) {
    snprintf(buf, sizeof(buf), "[LOCAL] Sol%d PWR%d", noteID, velocity);
    addLog(buf);
    triggerLocalSolenoidAsync(noteID - 1, velocity);
  } else {
    Serial.printf("N,%d,%d\n", noteID, velocity);
    snprintf(buf, sizeof(buf), "[UNO] N,%d,%d", noteID, velocity);
    addLog(buf);
  }
}

// --- HTTP handlers ---
void handleHit(AsyncWebServerRequest *request) {
  if (request->method() == AsyncWebRequestMethod::HTTP_OPTIONS) {
    request->send(200, "text/plain", ""); return;
  }
  if (request->hasArg("id") && request->hasArg("vel")) {
    playNote(request->arg("id").toInt(), request->arg("vel").toInt());
    request->send(200, "text/plain", "OK");
  } else {
    request->send(400, "text/plain", "Missing Parameters");
  }
}

void handleRoot(AsyncWebServerRequest *request) {
  char buf[80];
  snprintf(buf, sizeof(buf), "{\"status\":\"ONLINE\",\"ip\":\"%s\",\"heap\":%u}",
           WiFi.localIP().toString().c_str(), ESP.getFreeHeap());
  request->send(200, "application/json", buf);
}
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
